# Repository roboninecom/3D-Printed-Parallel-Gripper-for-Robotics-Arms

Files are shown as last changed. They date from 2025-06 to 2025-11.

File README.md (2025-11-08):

# 3D-Printed Parallel Gripper / SO-ARM 100

A precision parallel gripper designed by [Robonine](https://robonine.com) for robotics applications, featuring 3D-printed components and professional servo control using Feetech STS3215 servos.

---

<div align="center">

**Questions? We're here to help!**  
📩 Email: [hello@robonine.com](mailto:hello@robonine.com)

</div>

---

## 📸 Gallery

<div align="center">

### Assembled Gripper
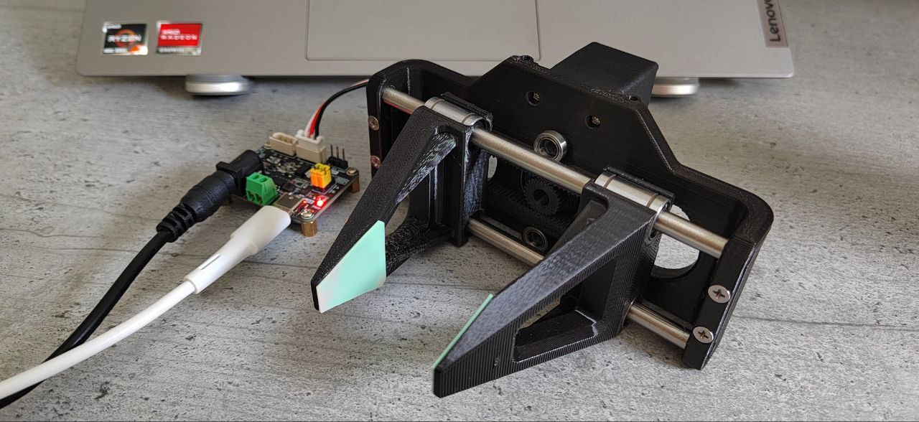
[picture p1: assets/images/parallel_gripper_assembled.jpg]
Assembled Parallel Gripper

*Real-world implementation of the gripper*

### 3D CAD Design
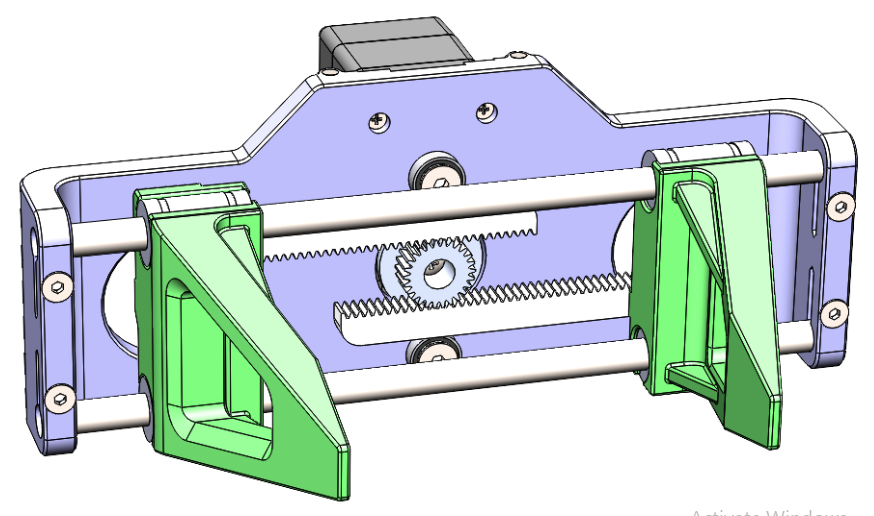
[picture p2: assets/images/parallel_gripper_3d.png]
3D CAD Model

*3D CAD design showing internal mechanism*

### 🎥 See It in Action


*Click above to see the parallel gripper working with precise control and smooth operation*

</div>

## 💰 Total Project Cost

**Complete Build Cost: $69.45-74.45** *(Amazon pricing)*

| Category | Cost (USD) |
|---|---|
| Electronic Components | $39.98 |
| Mechanical Components | $22.87 |
| 3D Printing Materials | $5-10 |
| Fasteners | $1.60 |
| **Total** | **$69.45-74.45** |

*All components available on Amazon with direct purchase links in [Bill of Materials](docs/bom-amazon.md)*

## 🎯 Project Overview

This project provides a complete open-source solution for a parallel gripper that can be integrated with robotic arms. The gripper features:

- **Precision Control**: Servo-driven parallel jaw mechanism with real-time feedback
- **Professional Design**: Industrial-grade part numbering and assembly procedures
- **Cost-Effective**: 3D-printed components with readily available hardware
- **Versatile Integration**: Compatible with various robotics platforms

## 🔧 Key Features

- **Parallel Jaw Movement**: Ensures consistent grip on objects of various sizes
- **Real-time Monitoring**: Current, voltage, temperature, and load feedback
- **Precise Positioning**: Degree-based control with position feedback (±0.1°)
- **Robust Construction**: Linear bearings for smooth, reliable operation
- **Professional Design**: CAD design with industrial-grade components
- **Servo Control**: High-torque Feetech STS3215 with bus communication
- **3D Printable**: All mechanical parts designed for standard FDM printers
- **Open Source**: Complete documentation, code, and CAD files included

## 📋 Specifications

- **Servo**: Feetech STS3215 (compatible with Waveshare variants)
- **Communication**: Serial (RS485/TTL, up to 1Mbps)
- **Power**: 6-12V DC
- **Jaw Travel**: Configurable based on gear ratio
- **Materials**: PLA/PETG 3D printed parts, steel rods, precision bearings
- **Positioning Accuracy**: ±0.1° (4096 steps/360°)
- **Force**: Up to 15kg·cm servo torque
- **Response Time**: <100ms for small movements

## 🎯 Performance Highlights

✅ **Smooth Operation** - Linear bearings ensure frictionless movement  
✅ **Precise Control** - Degree-based positioning with real-time feedback  
✅ **Reliable Gripping** - Parallel jaws maintain consistent contact  
✅ **Professional Integration** - Bus communication for robotics systems  
✅ **Proven Design** - Tested and demonstrated in real applications

## 🛠️ Hardware Requirements

### Electronic Components
- 1x Feetech STS3215-C018 Servo Motor or Waveshare STS3215
- 1x Bus Servo Adapter Board (Waveshare or compatible)

### Mechanical Components
- 2x MR106ZZ Bearings (10x6x3 mm)
- 4x LM6UU Linear Bearings (12x6x19 mm)
- 2x Stainless Steel Rods (6mm diameter, 150mm length)

### 3D-Printed Parts
- 1x Main Frame (RB9.01.060.010)
- 2x Clamps (RB9.01.060.020)
- 2x Gear Racks (RB9.01.060.030)
- 1x Drive Gear (RB9.01.060.040)

### Fasteners
- 4x M3x10 DIN 7991 screws
- 4x M3x20 DIN 7991 screws
- 2x M4x8 DIN 7991 screws
- 4x M3 DIN 934 nuts
- 4x Self-tapping screws (included with servo)

## 🚀 Quick Start

1. **Print the Parts**: Use the STL files in `/hardware/3d-models/`
2. **Gather Components**: Order parts from the [Bill of Materials](docs/bom.md)
3. **Assembly**: Follow the [Assembly Guide](docs/assembly-guide.md)
4. **Software Setup**: 
   - Download and install the STServo SDK:
     - Download [STServo Python SDK](https://files.waveshare.com/wiki/Bus-Servo-Adapter-(A)/STServo_Python.zip)
     - Extract the ZIP file and copy the `STservo_sdk` folder to `software/python/` directory
   - Install Python dependencies and run the control software:

```bash
pip install -r software/python/requirements.txt
python software/python/gripper_control.py
```

## 📁 Repository Structure

```
├── docs/                    # Documentation
│   ├── assembly-guide.md   # Step-by-step assembly
│   ├── bom.md             # Bill of materials
│   └── specifications.md   # Technical specifications
├── hardware/
│   └── 3d-models/         # STL files for 3D printing
├── software/
│   └── python/            # Control software
└── examples/              # Usage examples
```

## 🤝 Contributing

We welcome contributions! Please see our contributing guidelines for:
- Bug reports and feature requests
- Code contributions
- Documentation improvements
- Hardware modifications

## 📄 License

This project is licensed under the GPL-3.0 license - see the [LICENSE](LICENSE) file for details.

## 🔗 Links

- [Feetech STS3215 Servo](https://www.feetechrc.com/525603.html)
- [Waveshare Bus Servo Adapter](https://www.waveshare.com/bus-servo-adapter-a.htm)
- [Project Documentation](docs/)

## 📞 Support

For questions and support:
- Open an issue on GitHub
- Check the documentation in `/docs/`
- Review the examples in `/examples/`

---

<div align="center">

**Built for the robotics community by [Robonine](https://robonine.com)** 🤖

**Questions? We're here to help!**  
📩 Email: [hello@robonine.com](mailto:hello@robonine.com)

</div>

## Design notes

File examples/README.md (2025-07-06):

# Examples - Parallel Gripper

This directory contains example code demonstrating how to use the parallel gripper in various scenarios.

## Available Examples

### `basic_usage.py`
Demonstrates fundamental gripper operations:
- Connecting to the gripper
- Moving to specific positions
- Reading status information
- Basic error handling

**Usage:**
```bash
cd examples
python basic_usage.py
```

## Configuration

Before running examples, you may need to adjust configuration parameters:

```python
config = GripperConfig()
config.DEVICENAME = '/dev/ttyUSB0'  # Linux/Mac
# config.DEVICENAME = 'COM7'        # Windows
config.STS_ID = 1                   # Servo ID
config.BAUDRATE = 1000000          # Communication speed
```

## Common Issues

### Connection Problems
- **Windows**: Check Device Manager for correct COM port
- **Linux**: Ensure user has access to serial ports (`sudo usermod -a -G dialout $USER`)
- **macOS**: Use `/dev/cu.usbserial-*` or `/dev/tty.usbserial-*`

### Permission Errors
```bash
# Linux/macOS
sudo chmod 666 /dev/ttyUSB0
# or add user to dialout group
sudo usermod -a -G dialout $USER
```

### STServo SDK Issues
Make sure the STServo SDK is properly installed:
1. Download from: [STServo Python SDK](https://files.waveshare.com/wiki/Bus-Servo-Adapter-(A)/STServo_Python.zip)
2. Extract the downloaded ZIP file and copy the `STservo_sdk` folder (with the folder itself) to `software/python/` directory

## Creating Your Own Examples

When creating new examples:

1. **Import the gripper module**
   ```python
   from gripper_control import ParallelGripper, GripperConfig
   ```

2. **Handle errors gracefully**
   ```python
   try:
       gripper = ParallelGripper()
       if not gripper.connect():
           print("Connection failed!")
           return
       # Your code here
   finally:
       gripper.disconnect()
   ```

3. **Include proper documentation**
   - Clear description of what the example does
   - Required hardware setup
   - Expected behavior

## Safety Notes

⚠️ **Important Safety Considerations:**
- Always monitor temperature and current draw
- Implement proper error handling
- Test with low forces first
- Ensure proper mechanical setup
- Keep fingers clear of moving parts

## Contributing Examples

We welcome new examples! Please:
- Follow the existing code style
- Include comprehensive comments
- Test thoroughly before submitting
- Add entry to this README

---

**Happy coding!** 🤖

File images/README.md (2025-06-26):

# Images - Parallel Gripper

This directory contains visual documentation for the parallel gripper project.

## Files

### Product Photos
- **`parallel_gripper_assembled.jpg`** - Real-world photo of the assembled gripper
  - Shows the gripper in operational configuration
  - Demonstrates build quality and professional finish
  - Includes control electronics and cable management

### Technical Drawings
- **`parallel_gripper_3d.png`** - SolidWorks 3D CAD rendering
  - Professional technical visualization
  - Shows internal mechanism and component relationships
  - Demonstrates engineering design quality

## Video Documentation

### Demo Video
- **YouTube**: [Parallel Gripper in Action](https://youtube.com/shorts/Ss4TbO_psto?si=v6VbK91Q2vyNlbNd)
  - Real-time operation demonstration
  - Shows precision control capabilities
  - Demonstrates smooth parallel jaw movement

## Usage Guidelines

### For Documentation
- Use images in README files and documentation
- Maintain aspect ratios when resizing
- Provide descriptive alt text for accessibility

### For Presentations
- High-resolution images suitable for technical presentations
- Professional quality for academic or commercial use
- Clear demonstration of project capabilities

### For Social Media
- Engaging visuals for project promotion
- Video content for dynamic demonstration
- Professional appearance for credibility

## File Specifications

### Image Requirements
- **Format**: JPG/PNG for photos, PNG for technical drawings
- **Resolution**: Minimum 1920x1080 for documentation use
- **Quality**: High resolution for professional presentation
- **Compression**: Optimized for web while maintaining quality

### Video Requirements
- **Platform**: YouTube (embedded in documentation)
- **Duration**: Short-form content (under 60 seconds)
- **Quality**: HD minimum for clear demonstration
- **Content**: Clear demonstration of functionality

## Contributing Images

When adding new images:

1. **Naming Convention**: Use descriptive, lowercase filenames with underscores
2. **Quality Standards**: Ensure professional appearance and good lighting
3. **Documentation**: Update this README with new image descriptions
4. **Optimization**: Compress images appropriately for web use

### Photo Guidelines
- Good lighting and clear focus
- Clean background and professional setup
- Show key features and functionality
- Multiple angles if beneficial

### Technical Drawings
- High contrast and clear lines
- Proper scaling and dimensions
- Professional CAD rendering quality
- Clear component identification

---

**Visual documentation enhances project credibility and user understanding!** 📸

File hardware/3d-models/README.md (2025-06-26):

# 3D Models - Parallel Gripper

This directory contains all the STL files needed to 3D print the parallel gripper components.

## Files

| File | Part Number | Description | Quantity | Notes |
|---|---|---|---|---|
| `main-frame.stl` | RB9.01.060.010 | Main gripper frame | 1 | Houses servo and bearings |
| `clamp.stl` | RB9.01.060.020 | Gripper jaw/clamp | 2 | Contains LM6UU bearing seats |
| `gear-rack.stl` | RB9.01.060.030 | Linear gear rack | 2 | Converts rotation to linear motion |
| `drive-gear.stl` | RB9.01.060.040 | Drive gear | 1 | Mounts to servo output |

## 3D Printing Guidelines

### Recommended Settings
- **Layer Height**: 0.15-0.2mm
- **Infill**: 20% for frame/clamps, 30% for gears
- **Material**: PLA (prototyping), PETG (production)
- **Print Speed**: 50-60 mm/s
- **Nozzle Temperature**: 210°C (PLA), 240°C (PETG)
- **Bed Temperature**: 60°C (PLA), 80°C (PETG)

### Print Orientation
- **Main Frame**: Print upright for best surface finish
- **Clamps**: Print with bearing holes vertical
- **Gear Rack**: Print flat for best gear tooth quality
- **Drive Gear**: Print flat with gear teeth facing up

### Support Requirements
- **Main Frame**: Minimal supports may be needed
- **Clamps**: Supports required for bearing holes
- **Gear Rack**: No supports needed
- **Drive Gear**: No supports needed

### Post-Processing
1. **Remove supports** carefully to avoid damaging bearing seats
2. **Test fit bearings** - light sanding may be needed for proper fit
3. **Check gear mesh** - ensure smooth engagement between drive gear and racks
4. **Deburr all holes** for fasteners

## Material Considerations

### PLA (Recommended for Prototyping)
- ✅ Easy to print
- ✅ Good dimensional accuracy
- ✅ Low cost
- ❌ Limited temperature range
- ❌ Lower impact resistance

### PETG (Recommended for Production)
- ✅ Higher strength and flexibility
- ✅ Better temperature resistance
- ✅ Chemical resistance
- ❌ More challenging to print
- ❌ Higher cost

### ABS (Alternative)
- ✅ High strength
- ✅ Good temperature resistance
- ❌ Warping issues
- ❌ Requires heated enclosure

## Quality Control

### Dimensional Checks
- **Bearing fits**: LM6UU bearings should press-fit snugly
- **Rod clearance**: 6mm rods should slide smoothly
- **Gear mesh**: 0.2-0.3mm backlash between gears
- **Fastener holes**: M3/M4 screws should thread cleanly

### Functional Tests
1. **Bearing rotation**: All bearings should rotate freely
2. **Linear motion**: Clamps should slide smoothly on rods
3. **Gear engagement**: No binding or excessive noise
4. **Assembly fit**: All parts should assemble without force

## Troubleshooting

| Issue | Cause | Solution |
|---|---|---|
| Bearings too tight | Over-extrusion | Scale holes +2%, sand lightly |
| Bearings too loose | Under-extrusion | Use thread locker or shims |
| Gear binding | Poor print quality | Reprint with finer layer height |
| Rod binding | Warped parts | Check printer calibration |

## File Information

- **Format**: STL (binary)
- **Units**: Millimeters
- **Coordinate System**: Standard (Z-up)
- **Created With**: Professional CAD software
- **Tested**: Multiple print iterations

---

**Print responsibly and ensure proper ventilation when 3D printing!** 🖨️

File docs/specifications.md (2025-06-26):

# Technical Specifications

## Mechanical Specifications

### Overall Dimensions
- **Length**: ~150mm (rod length)
- **Width**: ~80mm (approximate frame width)
- **Height**: ~60mm (approximate frame height)
- **Weight**: ~200-300g (depending on infill and material)

### Gripper Performance
- **Maximum Opening**: Determined by rod length and gear ratio
- **Closing Force**: Servo-dependent (STS3215: ~15kg·cm torque)
- **Positioning Accuracy**: ±0.1° (servo resolution: 4096 positions/360°)
- **Speed**: Configurable, default 4800 units (adjustable in software)
- **Repeatability**: ±0.05° (typical for STS3215)

### Materials
- **3D Printed Parts**: PLA, PETG, ABS, or Nylon
- **Linear Rods**: Stainless steel 6mm diameter
- **Bearings**: Steel with lubrication
- **Fasteners**: Stainless steel (recommended)

## Electrical Specifications

### Servo Motor (Feetech STS3215)
- **Operating Voltage**: 6.0-12.6V DC
- **Current Draw**: 
  - Idle: ~100mA
  - Operating: 500-1500mA (load dependent)
  - Stall: ~2500mA (maximum)
- **Communication**: TTL/RS485 serial
- **Baud Rate**: Up to 1,000,000 bps
- **Protocol**: Feetech STS protocol
- **Position Resolution**: 4096 positions (0.088°/step)
- **Speed Range**: 0-2875 RPM
- **Torque**: 15kg·cm @ 12V

### Communication Interface
- **Protocol**: Custom Feetech STS protocol
- **Data Format**: 8N1 (8 data bits, no parity, 1 stop bit)
- **Flow Control**: None
- **Cable**: 4-wire (VCC, GND, DATA+, DATA-)
- **Connector**: JST or similar (servo dependent)

## Environmental Specifications

### Operating Conditions
- **Temperature Range**: -10°C to +50°C
- **Humidity**: 0-85% RH (non-condensing)
- **Altitude**: Up to 2000m
- **Vibration**: Light industrial environments

### Storage Conditions
- **Temperature Range**: -20°C to +60°C
- **Humidity**: 0-95% RH (non-condensing)

## Performance Characteristics

### Positioning
- **Resolution**: 0.088° per step (4096 steps/360°)
- **Accuracy**: ±0.1° (typical)
- **Repeatability**: ±0.05° (typical)
- **Backlash**: <0.2° (mechanical)

### Speed and Acceleration
- **Maximum Speed**: Configurable (default: 4800 units)
- **Acceleration**: Configurable (default: 5 units)
- **Response Time**: <100ms for small movements
- **Settling Time**: <500ms (typical)

### Force and Torque
- **Grip Force**: Depends on gear ratio and servo torque
- **Holding Force**: Full servo torque available
- **Maximum Load**: Limited by servo specifications

## Monitoring and Feedback

### Real-time Data Available
- **Position**: Current angular position (0-4095)
- **Speed**: Current rotational speed
- **Load**: Current load percentage (0-100%)
- **Temperature**: Servo internal temperature (°C)
- **Voltage**: Supply voltage (V)
- **Current**: Motor current draw (mA)

### Error Detection
- **Overload Protection**: Automatic shutdown on excessive load
- **Overtemperature Protection**: Thermal shutdown
- **Position Error Detection**: Deviation from target position
- **Communication Error Detection**: Protocol-level error checking

## Compliance and Standards

### Safety
- **Low Voltage**: Operates at safe voltage levels (<15V)
- **Mechanical Safety**: Rounded edges, no pinch points in normal operation
- **Electrical Safety**: Proper grounding and isolation recommended

### EMC (Electromagnetic Compatibility)
- **Emissions**: Low-level digital signals
- **Immunity**: Standard industrial levels
- **Recommendations**: Proper cable shielding for noisy environments

## Mounting and Integration

### Mounting Options
- **Robot Arm Interface**: Custom adapter plate required
- **Mounting Holes**: M4 or M5 (depending on design)
- **Orientation**: Any orientation supported
- **Cable Management**: Strain relief recommended

### Integration Requirements
- **Control System**: Any system supporting serial communication
- **Power Supply**: 6-12V DC, minimum 3A capacity
- **Communication**: TTL or RS485 interface
- **Software**: Python library provided, other languages possible

## Maintenance Requirements

### Regular Maintenance
- **Visual Inspection**: Monthly check for wear or damage
- **Screw Tightness**: Check quarterly
- **Bearing Lubrication**: Annual or as needed
- **Cable Inspection**: Check for wear or damage

### Replacement Parts
- **Bearings**: Standard sizes, readily available
- **Fasteners**: Standard metric screws
- **3D Printed Parts**: Can be reprinted as needed
- **Servo**: Feetech STS3215 or compatible

### Troubleshooting
- **Position Errors**: Check mechanical alignment
- **Communication Errors**: Verify connections and baud rate
- **Overheating**: Check load and duty cycle
- **Mechanical Binding**: Inspect bearings and alignment

---

**Specifications subject to change based on actual implementation and testing**

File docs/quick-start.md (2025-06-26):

# Quick Start Guide

Get your parallel gripper up and running in 30 minutes!

## 🎥 See the Final Result
Before you start, check out the [working gripper in action](https://youtube.com/shorts/Ss4TbO_psto?si=v6VbK91Q2vyNlbNd) to see what you'll be building!

## What You'll Need

### Hardware
- [ ] All 3D printed parts (see [3D Models](../hardware/3d-models/))
- [ ] Electronic components (see [BOM](bom.md))
- [ ] Mechanical components (bearings, rods, fasteners)
- [ ] Tools (screwdrivers, hex keys)

### Software
- [ ] Python 3.6+ installed
- [ ] STServo SDK downloaded
- [ ] Serial communication interface

## Step 1: 3D Print the Parts (2-4 hours)

1. Download STL files from `hardware/3d-models/`
2. Print with recommended settings:
   - Layer height: 0.2mm
   - Infill: 20% (frame/clamps), 30% (gears)
   - Material: PLA or PETG
3. Remove supports and test-fit bearings

## Step 2: Gather Components (1-2 days shipping)

Order parts from the [Bill of Materials](bom.md):
- Feetech STS3215 servo
- Waveshare bus servo adapter
- Bearings (2x MR106ZZ, 4x LM6UU)
- Steel rods (2x 6mm x 150mm)
- Fasteners (M3, M4 screws and nuts)

## Step 3: Assembly (30 minutes)

Follow the detailed [Assembly Guide](assembly-guide.md):

1. **Install bearings** in clamps (5 min)
2. **Mount gear** to servo (5 min)
3. **Attach servo** to main frame (5 min)
4. **Install frame bearings** (5 min)
5. **Add rods and clamps** (5 min)
6. **Attach gear racks** (5 min)

## Step 4: Software Setup (10 minutes)

1. **Install STServo SDK**
   ```bash
   git clone https://github.com/FEETECH-RC/STServo_SDK_Python.git
   cd STServo_SDK_Python
   cp -r STservo_sdk /path/to/your/project/
   ```

2. **Install Python dependencies**
   ```bash
   pip install -r software/python/requirements.txt
   ```

3. **Configure connection**
   Edit `software/python/gripper_control.py`:
   ```python
   DEVICENAME = 'COM7'  # Windows
   # DEVICENAME = '/dev/ttyUSB0'  # Linux
   STS_ID = 1  # Servo ID
   ```

## Step 5: First Test (5 minutes)

1. **Connect hardware**
   - Servo to bus adapter
   - Bus adapter to computer
   - Power supply (6-12V)

2. **Run basic test**
   ```bash
   cd software/python
   python gripper_control.py
   ```

3. **Try basic commands**
   - Enter `45` to open gripper
   - Enter `-45` to close gripper
   - Enter `0` to center
   - Press Enter to exit

## Step 6: Run Examples (5 minutes)

```bash
cd examples
python basic_usage.py
```

## Troubleshooting

### Connection Issues
- ✅ Check COM port in Device Manager (Windows)
- ✅ Verify servo power LED
- ✅ Try different baud rates
- ✅ Check cable connections

### Movement Issues
- ✅ Verify gear engagement
- ✅ Check for mechanical binding
- ✅ Ensure bearings move freely
- ✅ Monitor servo temperature

### Software Issues
- ✅ Install STServo SDK correctly
- ✅ Check Python version (3.6+)
- ✅ Verify serial port permissions (Linux)

## Next Steps

🎉 **Congratulations!** Your gripper is working!

Now you can:
- Integrate with your robot arm
- Modify the control software
- Create custom applications
- Share your projects with the community

## Need Help?

- 📖 Read the [full documentation](../README.md)
- 🐛 Report issues on GitHub
- 💬 Join community discussions
- 📧 Contact the maintainers

---

**Welcome to the parallel gripper community!** 🤖

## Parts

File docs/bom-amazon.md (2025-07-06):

# Bill of Materials (BOM) / Amazon

## Overview

This document lists all components required to build the parallel gripper. Links are provided to suggested suppliers, but equivalent parts from other vendors may be substituted.

## Electronic Components

| Item | Description | Qty | Supplier Link | Price |  Notes |
|---|---|-----|---|---|---|
| ST3215 Servo | Waveshare Servo Motor STS3215 | 1 | [Amazon – Waveshare STS3215 Servo](https://www.amazon.com/Precision-Programmable-Magnetic-Switchable-XYGStudy/dp/B0B95TFJ4H) | $28.99 | High-precision bus servo with feedback |
| Bus Servo Adapter | Waveshare Bus Servo Adapter Board | 1 | [Amazon – Bus Servo Adapter A](https://www.amazon.com/Waveshare-Integrates-Control-Applicable-Integrate/dp/B0CJ6TP3TP) | $10.99 | TTL/RS485 communication interface |

## Mechanical Components

### Bearings

| Item | Description | Qty | Supplier Link | Price | Notes |
|---|---|-----|---|---|---|
| MR106ZZ | Ball Bearing 10×6×3 mm | 2 | [Amazon – ACROPIX MR106ZZ Bearings (10pcs)](https://www.amazon.com/ACROPIX-Bearings-Shielded-Pre-Lubricated-Deep-6x10x3mm/dp/B0C4PGLSCY) | $5.49 (10pcs) | Shielded, pre-lubricated |
| LM6UU | Linear Bearing 6×12×19 mm | 4 | [Amazon – uxcell LM6UU Bearings (4pcs)](https://www.amazon.com/uxcell-LM6UU-Linear-Bearings-Length/dp/B07H95CWTX) | $8.99 (4pcs) | For smooth linear motion |

### Rods

| Item | Description | Qty | Supplier Link | Price | Notes |
|---|---|-----|---|---|---|
| Steel Rod | Stainless Steel Rod 6mm × 150mm | 2 | [Amazon – uxcell Stainless Steel Rod 6mm×150mm (5pcs)](https://www.amazon.com/uxcell-150mm-Stainless-Steel-Solid/dp/B082ZP51W8) | $8.39 (5pcs) | High precision, corrosion resistant |

## 3D-Printed Parts

| Part Number | Description | Qty | Material | Print Settings |
|---|---|-----|---|---|
| RB9.01.060.010 | Main Frame | 1 | PLA/PETG | 0.2mm layer, 20% infill |
| RB9.01.060.020 | Clamp | 2 | PLA/PETG | 0.2mm layer, 20% infill |
| RB9.01.060.030 | Gear Rack | 2 | PLA/PETG | 0.15mm layer, 30% infill |
| RB9.01.060.040 | Drive Gear | 1 | PLA/PETG | 0.15mm layer, 30% infill |

### 3D Printing Notes
- **Material**: PLA recommended for prototyping, PETG for production use
- **Layer Height**: 0.15-0.2mm for optimal surface finish
- **Infill**: Higher infill (30%) recommended for gears to ensure strength
- **Support**: May be required depending on printer orientation
- **Post-processing**: Light sanding may be needed for bearing fits

## Fasteners

### Screws

| Item | Description | Qty | Standard | Price | Notes |
|---|---|-----|---|---|---|
| M3×10 | Countersunk Screw | 4 | [Amazon – M3×10 Countersunk Screws](https://www.amazon.com/dp/B07JW9XF4Z) | $6.39 (100pcs) | For gear rack attachment |
| M3×20 | Countersunk Screw | 4 | [Amazon – M3×20 Countersunk Screws](https://www.amazon.com/dp/B0C6Z6DJ7V) | $6.99 (100pcs) | For clamp to rod attachment |
| M4×8 | Countersunk Screw | 2 | [Amazon – M4×8 Countersunk Screws](https://www.amazon.com/dp/B07JHD5YMV) | $9.99 (100pcs) | For main frame bearing retention |

### Nuts

| Item | Description | Qty | Standard | Price | Notes |
|---|---|-----|---|---|---|
| M3 | Hex Nut | 4 | [Amazon – M3 Hex Nuts](https://www.amazon.com/dp/B07T7NCS7D) | $5.99 (100pcs) | For clamp assembly |

### Servo Hardware

| Item | Description | Qty | Source | Price | Notes |
|---|---|-----|---|---|---|
| Self-tapping Screws | Servo mounting screws | 4 | Servo kit | Included | Included with STS3215 |
| Servo Disk | Output shaft adapter | 1 | Servo kit | Included | Included with STS3215 |
| Mounting Screw | Disk retention screw | 1 | Servo kit | Included | Included with STS3215 |

## Cost Estimate

| Category | Estimated Cost (USD) |
|---|---|
| Electronic Components | $39.98 |
| Mechanical Components | $22.87 |
| 3D Printing Materials | $5-10 |
| Fasteners | $1.60 (approximate) |
| **Total** | **$69.45-74.45** |

*Costs based on Amazon pricing as of current date - 6th of June 2025. Bulk quantities provide significant savings on fasteners.*

## Sourcing Notes

### Alternative Suppliers
- **Bearings**: Local industrial suppliers often carry standard sizes
- **Rods**: Machine shops can cut custom lengths
- **Fasteners**: McMaster-Carr, Fastenal, or local hardware stores
- **Electronics**: Robotics specialty suppliers may offer better pricing

### Quality Considerations
- **Bearings**: Ensure proper ABEC rating for smooth operation
- **Rods**: Straightness tolerance critical for proper operation
- **Fasteners**: Stainless steel recommended for corrosion resistance

### Bulk Ordering
- Consider ordering extra fasteners for future builds
- 3D printing multiple sets reduces per-unit cost
- Group orders with robotics clubs/makerspaces for better pricing

## Compatibility Notes

### Servo Alternatives
The gripper is designed for the Feetech STS3215, but may be compatible with:
- Other Feetech STS series servos (with mounting modifications)
- Waveshare ST3215 (direct compatibility)
- Similar bus servos with 25T spline output

### Material Substitutions
- **Rods**: Carbon fiber or aluminum possible for weight reduction
- **Bearings**: Ceramic bearings for high-precision applications
- **3D Printing**: ABS, ASA, or Nylon for high-temperature environments

---

**Procurement Complete!** You should now have all components needed for assembly.

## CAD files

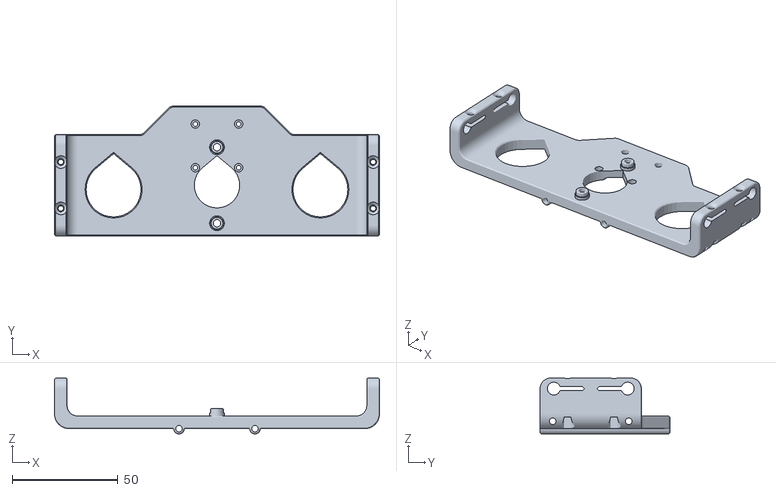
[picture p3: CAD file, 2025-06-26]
hardware/3d-models/main-frame.stl
154.0 x 61.5 x 26.5

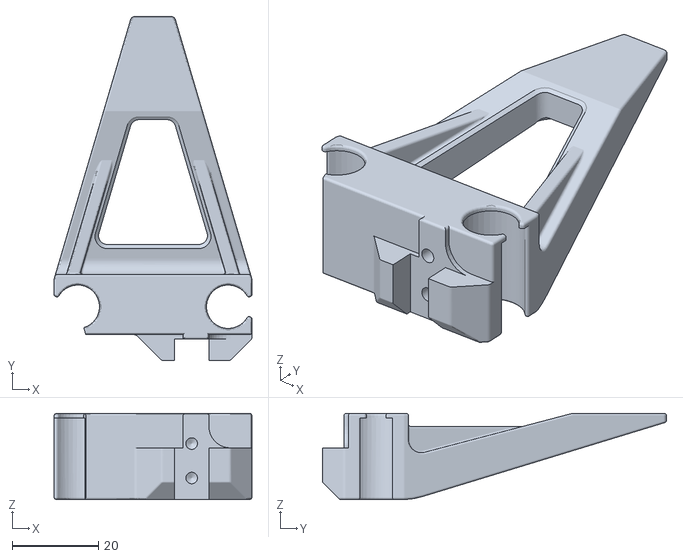
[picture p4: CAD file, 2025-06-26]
hardware/3d-models/clamp.stl
46.0 x 80.0 x 20.0

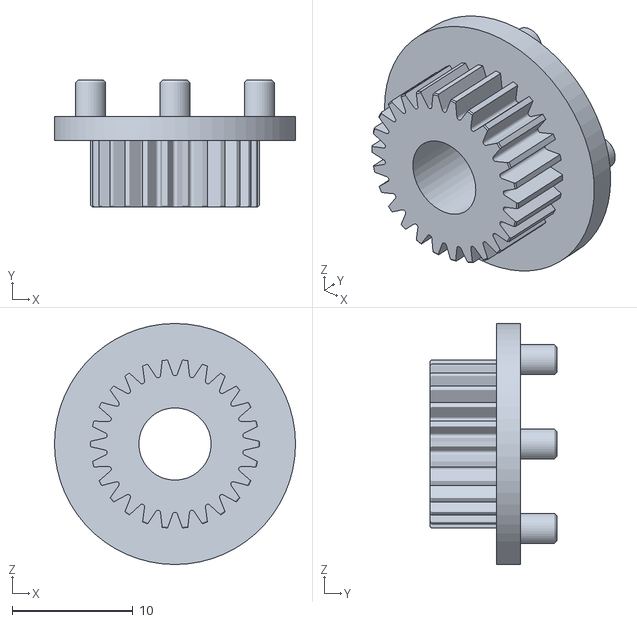
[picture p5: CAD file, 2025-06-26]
hardware/3d-models/drive-gear.stl
20.0 x 10.5 x 20.0

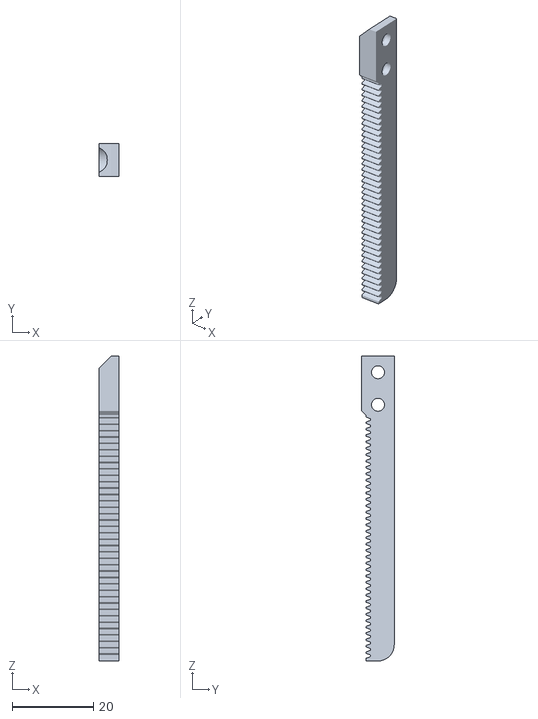
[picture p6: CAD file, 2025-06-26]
hardware/3d-models/gear-rack.stl
5.00 x 8.00 x 75.0

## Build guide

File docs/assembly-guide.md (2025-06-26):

# Assembly Guide

## Overview

This guide provides step-by-step instructions for assembling the parallel gripper. Follow these steps carefully to ensure proper operation.

## Required Tools

- Phillips head screwdriver
- Hex key set (M3, M4)
- Small pliers (for handling bearings)

## Safety Precautions

- Handle bearings carefully to avoid contamination
- Ensure all screws are properly tightened but not over-torqued
- Test servo operation before final assembly

## Assembly Steps

### Step 1: Install Linear Bearings in Clamps

**Components needed:**
- 2x Clamps (RB9.01.060.020)
- 4x LM6UU Linear Bearings (12x6x19 mm)

**Instructions:**
1. Take the first clamp part
2. Carefully press 2x LM6UU bearings into the designated bearing seats
3. Ensure bearings are fully seated and can rotate freely
4. Repeat for the second clamp
5. **Note**: Bearings should slide smoothly without binding

### Step 2: Prepare Servo and Drive Gear

**Components needed:**
- 1x Feetech STS3215 Servo
- 1x Drive Gear (RB9.01.060.040)
- 1x Servo disk (from servo kit)
- 1x Servo mounting screw (from servo kit)

**Instructions:**
1. Insert the Drive Gear into the servo disk from the servo kit
2. Align the gear teeth properly with the disk
3. Mount the gear assembly onto the servo output shaft
4. Secure with the screw provided in the servo kit
5. **Important**: Ensure the gear is properly aligned and rotates smoothly

### Step 3: Mount Servo to Main Frame

**Components needed:**
- 1x Main Frame (RB9.01.060.010)
- 1x Assembled servo with gear
- 4x Self-tapping screws (from servo kit)

**Instructions:**
1. Position the servo in the designated mounting area on the main frame
2. Align the servo mounting holes with the frame
3. Secure the servo using 4x self-tapping screws from the servo kit
4. **Check**: Servo should be firmly mounted with no play

### Step 4: Install Main Frame Bearings

**Components needed:**
- 2x MR106ZZ Bearings (10x6x3 mm)
- 2x M4x8 DIN 7991 screws

**Instructions:**
1. Insert the 2x MR106ZZ bearings into their designated positions on the main frame
2. These bearings will guide the linear rods
3. Secure each bearing with 1x M4x8 screw
4. **Note**: Do not over-tighten; bearings should rotate freely

### Step 5: Install Rods and Clamps

**Components needed:**
- 2x Stainless Steel Rods (6mm diameter, 150mm length)
- 2x Assembled clamps (with LM6UU bearings)
- 4x M3x20 DIN 7991 screws
- 4x M3 DIN 934 nuts

**Instructions:**
1. Insert the 2x steel rods through the main frame bearings
2. Slide the 2x clamps onto the rods (LM6UU bearings should slide smoothly)
3. Position the clamps symmetrically from the center of the main frame
4. Secure each clamp to the rods using 2x M3x20 screws and 2x M3 nuts per clamp
5. **Critical**: Ensure clamps move smoothly along the rods

### Step 6: Attach Gear Racks

**Components needed:**
- 2x Gear Racks (RB9.01.060.030)
- 4x M3x10 DIN 7991 screws

**Instructions:**
1. Position the gear racks on the back side of each clamp
2. **Important**: Ensure clamps remain symmetrically positioned from the main frame center
3. The gear racks should engage properly with the drive gear
4. Secure each gear rack with 2x M3x10 screws
5. **Test**: Manually rotate the servo to verify smooth gear engagement

## Final Checks

### Mechanical Verification
- [ ] All screws are properly tightened
- [ ] Clamps move smoothly along the rods
- [ ] Gear engagement is smooth without binding
- [ ] No excessive play in any joints
- [ ] Bearings rotate freely

### Electrical Connection
- [ ] Servo connector is properly seated
- [ ] Bus servo adapter is connected
- [ ] Power supply is appropriate (6-12V DC)

### Functional Test
1. Connect the servo to your control system
2. Run the test software to verify operation
3. Check for smooth movement and proper positioning
4. Monitor servo feedback (current, temperature, load)

## Troubleshooting

| Issue | Possible Cause | Solution |
|---|---|---|
| Clamps bind on rods | Misaligned bearings | Check LM6UU bearing installation |
| Gear noise/binding | Poor gear engagement | Adjust gear rack position |
| Servo errors | Electrical connection | Verify wiring and power supply |
| Uneven movement | Asymmetric assembly | Check clamp positioning |

## Maintenance

- **Regular**: Check screw tightness
- **Monthly**: Clean and lubricate bearings if needed
- **As needed**: Monitor servo temperature and current draw

---

**Assembly Complete!** Your parallel gripper is now ready for integration and testing.

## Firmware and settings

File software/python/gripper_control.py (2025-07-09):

#!/usr/bin/env python3
"""
Parallel Gripper Control Software
=================================

Professional control software for the open-source parallel gripper using
Feetech STS3215 servo motors. Provides real-time control, monitoring, and
feedback for robotics applications.

Features:
- Precise position control with degree-based input
- Real-time monitoring (position, current, voltage, temperature, load)
- Cross-platform compatibility (Windows, Linux, macOS)
- Interactive control interface
- Comprehensive error handling

Requirements:
- STServo SDK (https://github.com/FEETECH-RC/STServo_SDK_Python)
- Python 3.6+
- Serial communication interface

Author: Open-Source Parallel Gripper Project
License: MIT
"""

import sys
import os
import time
import logging
from typing import Tuple, Optional
import serial.tools.list_ports
from pathlib import Path 

# Cross-platform keyboard input handling
if os.name == 'nt':
    import msvcrt
    def getch():
        """Get single character input (Windows)"""
        return msvcrt.getch().decode()
else:
    import tty, termios
    def getch():
        """Get single character input (Unix/Linux/macOS)"""
        fd = sys.stdin.fileno()
        old_settings = termios.tcgetattr(fd)
        try:
            tty.setraw(fd)
            return sys.stdin.read(1)
        finally:
            termios.tcsetattr(fd, termios.TCSADRAIN, old_settings)

# Graceful SDK path handling using pathlib
sdk_path = Path(__file__).resolve().parent.parent / "STservo_sdk"
sys.path.append(str(sdk_path))

try:
    from STservo_sdk import *
except ImportError:
    print("Error: STServo SDK not found!")
    print("Please install STServo SDK from: https://github.com/FEETECH-RC/STServo_SDK_Python")
    print("Copy the STservo_sdk folder to your project directory or Python path.")
    sys.exit(1)

# Dynamic COM port selection
print("\n🔌 Available COM ports:")
ports = list(serial.tools.list_ports.comports())
if not ports:
    print("❌ No COM ports found. Please connect your device and try again.")
    sys.exit(1)
for idx, port in enumerate(ports):
    print(f"  [{idx}] {port.device}")

choice = input("Select port number (default 0): ").strip()
SELECTED_PORT = ports[int(choice)].device if choice.isdigit() and int(choice) < len(ports) else ports[0].device

# Configuration Constants
class GripperConfig:
    """Configuration parameters for the parallel gripper"""
    
    # Servo Configuration
    STS_ID = 1                  # Servo ID (can be changed if multiple servos)
    BAUDRATE = 1000000         # Communication baud rate (1 Mbps)
    DEVICENAME = SELECTED_PORT  # Dynamic port from user selection
    
    # Motion Parameters
    MAX_DEGREE = 360           # Maximum rotation (degrees)
    MAX_POSITION = 4095        # Maximum position value (12-bit resolution)
    DEFAULT_SPEED = 4800       # Default movement speed
    DEFAULT_ACCELERATION = 5   # Default acceleration
    
    # Monitoring Parameters
    LSB_TO_mA = 2700 / 2047   # Current conversion factor (~1.32 mA per LSB)
    VOLTAGE_SCALE = 0.1       # Voltage scale factor (0.1V per LSB)
    LOAD_SCALE = 100 / 2047   # Load percentage scale factor
    
    # Safety Limits
    MAX_TEMPERATURE = 70      # Maximum safe temperature (°C)
    MAX_CURRENT = 2000        # Maximum safe current (mA)
    
    # Update Intervals
    MONITOR_INTERVAL = 0.05   # Monitoring update interval (seconds)

class ParallelGripper:
    """
    Main class for controlling the parallel gripper
    
    Provides high-level interface for gripper control, monitoring, and safety.
    """
    
    def __init__(self, config: GripperConfig = None):
        """
        Initialize the gripper controller
        
        Args:
            config: Configuration object (uses default if None)
        """
        self.config = config or GripperConfig()
        self.port_handler = None
        self.packet_handler = None
        self.is_connected = False
        
        # Setup logging
        logging.basicConfig(level=logging.INFO, 
                          format='%(asctime)s - %(levelname)s - %(message)s')
        self.logger = logging.getLogger(__name__)
    
    def connect(self) -> bool:
        """
        Establish connection to the servo
        
        Returns:
            bool: True if connection successful, False otherwise
        """
        try:
            self.port_handler = PortHandler(self.config.DEVICENAME)
            self.packet_handler = sts(self.port_handler)
            
            if not self.port_handler.openPort():
                self.logger.error(f"Failed to open port {self.config.DEVICENAME}")
                return False
            
            if not self.port_handler.setBaudRate(self.config.BAUDRATE):
                self.logger.error(f"Failed to set baud rate to {self.config.BAUDRATE}")
                return False
            
            # Set servo to position control mode
            self.packet_handler.write1ByteTxRx(self.config.STS_ID, 33, 0)
            
            self.is_connected = True
            self.logger.info(f"Connected to servo ID {self.config.STS_ID} on {self.config.DEVICENAME}")
            return True
            
        except Exception as e:
            self.logger.error(f"Connection failed: {e}")
            return False
    
    def disconnect(self):
        """Close the connection to the servo"""
        if self.port_handler and self.is_connected:
            self.port_handler.closePort()
            self.is_connected = False
            self.logger.info("Disconnected from servo")
    
    def degrees_to_position(self, degrees: float) -> int:
        """
        Convert degrees to servo position value
        
        Args:
            degrees: Angle in degrees (can be negative)
            
        Returns:
            int: Servo position value (0-4095)
        """
        degrees = degrees % self.config.MAX_DEGREE
        return int((degrees / self.config.MAX_DEGREE) * self.config.MAX_POSITION)
    
    def position_to_degrees(self, position: int) -> float:
        """
        Convert servo position value to degrees
        
        Args:
            position: Servo position value (0-4095)
            
        Returns:
            float: Angle in degrees
        """
        return (position / self.config.MAX_POSITION) * self.config.MAX_DEGREE
    
    def move_to_angle(self, angle: float, speed: int = None, acceleration: int = None) -> bool:
        """
        Move gripper to specified angle
        
        Args:
            angle: Target angle in degrees
            speed: Movement speed (uses default if None)
            acceleration: Movement acceleration (uses default if None)
            
        Returns:
            bool: True if command sent successfully, False otherwise
        """
        if not self.is_connected:
            self.logger.error("Not connected to servo")
            return False
        
        speed = speed or self.config.DEFAULT_SPEED
        acceleration = acceleration or self.config.DEFAULT_ACCELERATION
        
        goal_position = self.degrees_to_position(angle)
        
        try:
            result, error = self.packet_handler.WritePosEx(
                self.config.STS_ID, goal_position, speed, acceleration
            )
            
            if result != COMM_SUCCESS:
                self.logger.error(f"Communication error: {self.packet_handler.getTxRxResult(result)}")
                return False
            
            if error != 0:
                self.logger.error(f"Servo error: {self.packet_handler.getRxPacketError(error)}")
                return False
            
            self.logger.info(f"Moving to {angle:.1f}° (position {goal_position})")
            return True
            
        except Exception as e:
            self.logger.error(f"Move command failed: {e}")
            return False
    
    def get_status(self) -> Optional[dict]:
        """
        Get current servo status and telemetry
        
        Returns:
            dict: Status information or None if error
        """
        if not self.is_connected:
            return None
        
        try:
            # Current position
            position, _, _ = self.packet_handler.ReadPos(self.config.STS_ID)
            degrees = self.position_to_degrees(position)
            
            # Current draw
            current_raw, _, _ = self.packet_handler.read2ByteTxRx(self.config.STS_ID, 69)
            current = self.packet_handler.sts_tohost(current_raw, 15)
            current_mA = current * self.config.LSB_TO_mA
            
            # Supply voltage
            voltage_raw, _, _ = self.packet_handler.read1ByteTxRx(self.config.STS_ID, 62)
            voltage = voltage_raw * self.config.VOLTAGE_SCALE
            
            # Load percentage
            load_raw, _, _ = self.packet_handler.read2ByteTxRx(self.config.STS_ID, 60)
            load_percent = int(round(load_raw * self.config.LOAD_SCALE))
            
            # Temperature
            temperature, _, _ = self.packet_handler.read1ByteTxRx(self.config.STS_ID, 63)
            
            # Movement status
            is_moving, _, _ = self.packet_handler.ReadMoving(self.config.STS_ID)
            
            return {
                'position': position,
                'degrees': degrees,
                'current_raw': current,
                'current_mA': current_mA,
                'voltage': voltage,
                'load_percent': load_percent,
                'temperature': temperature,
                'is_moving': bool(is_moving)
            }
            
        except Exception as e:
            self.logger.error(f"Status read failed: {e}")
            return None
    
    def wait_for_completion(self, target_position: int, timeout: float = 10.0) -> bool:
        """
        Wait for movement to complete with real-time monitoring
        
        Args:
            target_position: Expected final position
            timeout: Maximum wait time in seconds
            
        Returns:
            bool: True if movement completed successfully
        """
        start_time = time.time()
        
        print("🟡 Movement in progress... (Press Ctrl+C to stop)\n")
        
        try:
            while time.time() - start_time < timeout:
                time.sleep(self.config.MONITOR_INTERVAL)
                
                status = self.get_status()
                if not status:
                    return False
                
                # Display status
                print(f" → Target: {target_position:4d} | "
                      f"Position: {status['position']:4d} ({status['degrees']:6.1f}°) | "
                      f"Current: {status['current_raw']:3d} ({status['current_mA']:.0f}mA) | "
                      f"Load: {status['load_percent']:2d}% | "
                      f"Temp: {status['temperature']}°C")
                
                # Safety checks
                if status['temperature'] > self.config.MAX_TEMPERATURE:
                    self.logger.warning(f"High temperature: {status['temperature']}°C")
                
                if status['current_mA'] > self.config.MAX_CURRENT:
                    self.logger.warning(f"High current: {status['current_mA']:.0f}mA")
                
                # Check if movement completed
                if not status['is_moving']:
                    print("✅ Movement completed\n")
                    return True
            
            self.logger.warning("Movement timeout")
            return False
            
        except KeyboardInterrupt:
            print("\n⏹️ Movement interrupted by user")
            return False
    
    def interactive_control(self):
        """Run interactive control interface"""
        print("\n" + "="*60)
        print("🤖 PARALLEL GRIPPER CONTROL INTERFACE")
        print("="*60)
        print(f"Servo ID: {self.config.STS_ID}")
        print(f"Port: {self.config.DEVICENAME}")
        print(f"Baud Rate: {self.config.BAUDRATE}")
        print("-"*60)
        print("Commands:")
        print("  • Enter angle in degrees (positive or negative)")
        print("  • Press Enter (empty) to exit")
        print("  • Ctrl+C to interrupt movement")
        print("="*60)
        
        try:
            while True:
                user_input = input("\nEnter target angle (degrees): ").strip()
                
                if not user_input:
                    print("👋 Exiting...")
                    break
                
                try:
                    angle = float(user_input)
                    target_position = self.degrees_to_position(angle)
                    
                    if self.move_to_angle(angle):
                        self.wait_for_completion(target_position)
                    
                except ValueError:
                    print("❌ Invalid input. Please enter a number.")
                except Exception as e:
                    self.logger.error(f"Control error: {e}")
                    
        except KeyboardInterrupt:
            print("\n👋 Control interface interrupted")

def main():
    """Main function - entry point for the application"""
    print("🚀 Starting Parallel Gripper Control Software...")
    
    # Create gripper instance
    gripper = ParallelGripper()
    
    try:
        # Connect to servo
        if not gripper.connect():
            print("❌ Failed to connect to servo. Please check:")
            print("  • Port name (currently: {})".format(gripper.config.DEVICENAME))
            print("  • Servo power and connections")
            print("  • Servo ID (currently: {})".format(gripper.config.STS_ID))
            print("  • Baud rate (currently: {})".format(gripper.config.BAUDRATE))
            return 1
        
        # Run interactive control
        gripper.interactive_control()
        
    except Exception as e:
        print(f"❌ Unexpected error: {e}")
        return 1
    
    finally:
        # Ensure clean shutdown
        gripper.disconnect()
    
    return 0

if __name__ == "__main__":
    sys.exit(main())

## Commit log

2025-06-26 Enhance README and quick-start documentation with a gallery, performance highlights, and a demo video link to showcase the parallel gripper's features and capabilities.
2025-07-01 chore: Refine language in README for clarity and conciseness, updating descriptions of the gripper's real-world implementation and CAD design.
2025-07-06 docs: Updated BOM with links from Amazon
2025-07-06 docs: Fix table formatting in BOM for electronic components and bearings
2025-07-06 docs: Add project cost breakdown and update gripper model description in README
2025-07-06 docs: Update supplier link and cost date in BOM for ST3215 Servo
2025-07-08 added dynamic COM port selection and robust SDK path handling
    - Replaced hardcoded 'COM7' with dynamic user-selected COM port using serial.tools.list_ports
    - Added fallback and error message when no COM ports are detected
    - Replaced sys.path.append("..") with pathlib-based SDK path resolution for cross-platform safety
    [gripper_control.py]
2025-10-14 feat: Add gripper 3D model in STEP format
